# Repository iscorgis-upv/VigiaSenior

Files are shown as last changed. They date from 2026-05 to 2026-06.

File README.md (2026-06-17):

# VigiaSenior

<p align="center">
  <strong>Programación de aula y desarrollo técnico de un backend IoT para el seguimiento de la medicación en personas mayores</strong>
</p>

<p align="center">
  <em>CFGS Desarrollo de Aplicaciones Web (DAW) · Módulo 0613 - Desarrollo web en entorno servidor</em>
</p>

---
> **Nota de navegación**  
> Este README resume el contenido principal del repositorio, pero para revisar el proyecto con mejor estructura visual, navegación entre apartados y acceso ordenado a los materiales, se recomienda consultar la versión publicada en **GitHub Pages**:  
>  
> 👉 **https://iscorgis-upv.github.io/VigiaSenior/**  
>  
> El repositorio contiene muchos materiales conectados entre sí: documentación para profesorado, materiales para alumnado, implementación técnica, presentación, hardware y simulación. GitHub Pages facilita bastante su lectura.

---

## 🧭 Introducción

Este repositorio recoge una programación de aula del **CFGS de Desarrollo de Aplicaciones Web (DAW)** para el módulo **0613 · Desarrollo web en entorno servidor**. En esta propuesta didáctica se desarrolla el proyecto **VigiaSenior**, articulado a partir de una unidad de trabajo basada en el diseño e implementación del **backend de un pastillero inteligente**, pensado para apoyar el seguimiento de la medicación en personas mayores.

La propuesta parte de un problema real y reconocible: La dificultad de mantener rutinas de medicación seguras, controladas y registrables en contextos de envejecimiento, dependencia o supervisión familiar. A partir de ese contexto, el alumnado desarrolla una solución tecnológica en la que convergen análisis, modelado de datos, servicios web, lógica de negocio, persistencia, documentación e integración básica con hardware o simulación.

> **El repositorio tiene dos objetivos principales:**
>
> - Servir como **programación de aula transferible**, para que otro docente pueda comprenderla y aplicarla con pocas modificaciones.
> - Actuar como **repositorio técnico del proyecto**, recogiendo backend, hardware, simulación, documentación técnica y materiales de apoyo.

## 🎓 Normativa y contexto académico

Para elaborar esta propuesta se ha tomado como referencia la normativa del sistema educativo y de Formación Profesional, así como la normativa específica del título de **Técnico Superior en Desarrollo de Aplicaciones Web** y la normativa curricular aplicable en la **Comunidad Valenciana**.

La normativa completa puede consultarse en [Contextualización y marco legal](./profesorado/02_contextualizacion_y_marco_legal.html).

| Campo | Descripción |
|---|---|
| Etapa | Formación Profesional |
| Ciclo | CFGS Desarrollo de Aplicaciones Web (DAW) |
| Módulo | 0613 · Desarrollo web en entorno servidor |
| Metodología principal | Aprendizaje Basado en Proyectos (ABP) |
| Enfoque complementario | Aprendizaje-Servicio (ApS) |
| Producto técnico | Backend IoT para seguimiento de medicación |

A nivel curricular, el proyecto encaja bien con el módulo porque reúne varias tareas habituales del desarrollo backend: Crear servicios web, trabajar con una base de datos, organizar la lógica de negocio y diseñar una API. El componente IoT se utiliza como contexto del problema, no como objetivo principal, y sirve para dar sentido a los eventos que recibe el sistema. Además, el alumnado debe documentar lo que hace y defender las decisiones tomadas en la exposición final.

## 🧩 Proyecto

En esta propuesta se desarrolla **VigiaSenior**, un backend para un pastillero inteligente pensado para ayudar en el seguimiento de la medicación en personas mayores. Se trata de un proyecto que parte de una necesidad real y da sentido a los contenidos del módulo mediante una aplicación práctica con trasfondo social.

Su encaje dentro de **Desarrollo web en entorno servidor** es claro, ya que permite trabajar servicios web, bases de datos, lógica de negocio, diseño de endpoints e integración de eventos procedentes de un dispositivo. En lugar de abordar estos contenidos por separado, se trabajan de manera conjunta dentro de un proyecto único, más cercano a una situación real de desarrollo.

## 🎯 Objetivos del proyecto

Con esta propuesta se pretende que el alumnado sea capaz de:

- Analizar un problema real y convertirlo en requisitos técnicos.
- Diseñar el modelo de dominio de una aplicación basada en eventos.
- Estructurar una API  coherente y documentada.
- Implementar la persistencia de datos mediante base de datos relacional.
- Desarrollar lógica de negocio en servidor.
- Integrar software y hardware en una arquitectura sencilla de IoT.
- Documentar el proyecto de forma clara, trazable y reutilizable.
- Presentar el proyecto y explicar por qué se han tomado las principales decisiones técnicas y didácticas.

## 🚀 Resultado esperado del proyecto

Al finalizar el proyecto, el alumnado habrá desarrollado una primera versión funcional del backend de VigiaSenior, capaz de gestionar la planificación diaria de tomas, recibir eventos simulados de un dispositivo y registrar lo que ocurre durante el seguimiento de la medicación.

El proyecto se apoya en un flujo funcional sencillo, pero suficientemente sólido para trabajarlo en el aula:

- Consulta de planificación diaria.
- Recepción de eventos del dispositivo.
- Registro de apertura de cajita.
- Confirmación de la toma.
- actualización del estado de la toma.
- Generación de alertas.
- Consulta básica de seguimiento e histórico.

### Endpoints principales del backend

```text
GET   /health
GET   /api/devices/:deviceId/schedule/today
POST  /api/devices/:deviceId/events
GET   /api/patients/:patientId/dashboard
GET   /api/patients/:patientId/alerts
PATCH /api/alerts/:alertId/resolve
```

## 🔌 Hardware del proyecto

La parte física se plantea en una versión simplificada y asumible para aula, basada en **Arduino Nano ESP32**. Se entrega al inicio del proyecto porque la finalidad principal de la propuesta es el **backend**, no la electrónica ni la configuración hardware.

Se ha elegido una placa basada en ESP32, como Arduino Nano ESP32, porque ofrece un equilibrio muy adecuado entre coste, tamaño y conectividad. Es una opción asequible y fácil de conseguir, también en versiones compatibles de bajo coste, lo que la hace razonable para el contexto academico.

Además, su tamaño reducido encaja mejor en un prototipo de pastillero que otras alternativas más voluminosas, y además integra Wi-Fi y Bluetooth en la propia placa. Esto simplifica mucho el proyecto, ya que evita recurrir a módulos externos adicionales o a soluciones más costosas y complejas, como podría ocurrir con otras placas o con una Raspberry Pi.

### Configuración del prototipo

- 6 pulsadores o sensores para simular la apertura de las cajitas;
- 6 LEDs de estado;
- 1 botón de confirmación;
- 1 buzzer;
- conexión Wi‑Fi en la versión con backend.

### Esquema Propuesto

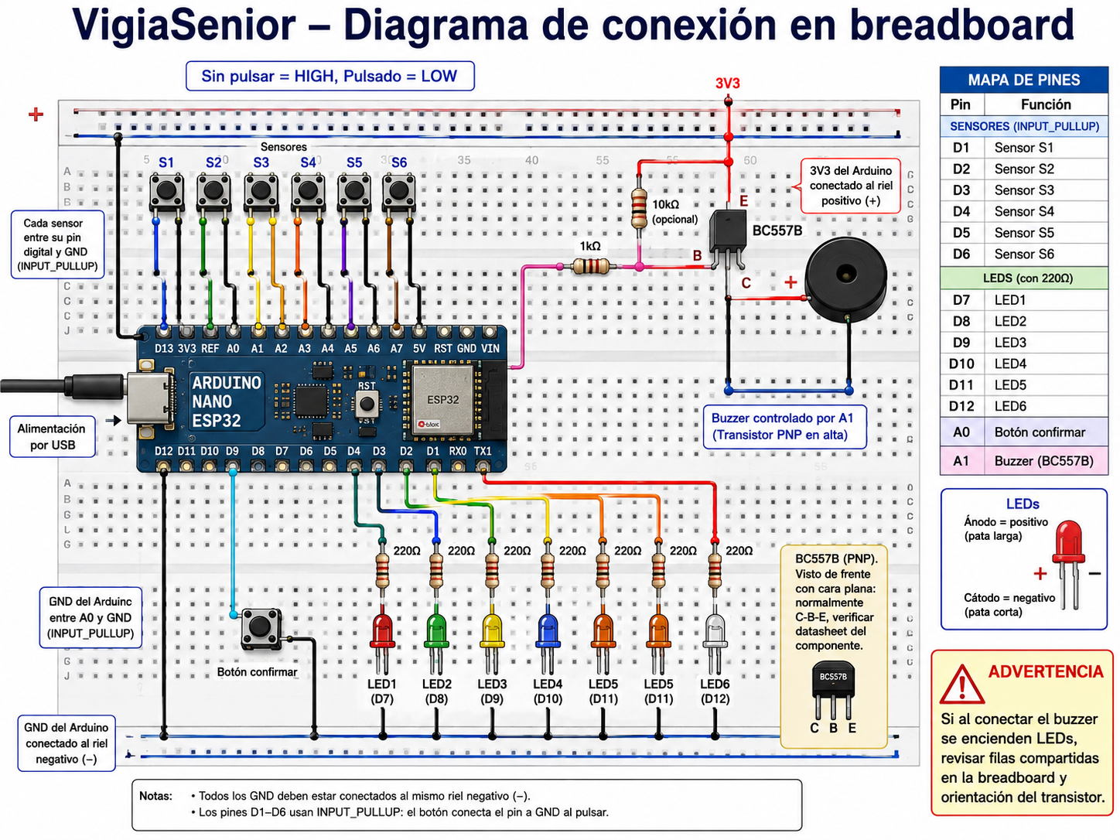
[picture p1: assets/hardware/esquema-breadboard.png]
Esquema de conexión en breadboard


## 🗂️ Estructura del repositorio

La estructura del repositorio se ha organizado para que la parte **didáctica** y la parte **técnica** convivan sin mezclarse.

```text
VigiaSenior/
├── alumnado/
├── profesorado/
├── presentacion/
├── implementacion/
├── LICENSE
└── README.md
```

| Carpeta | Contenido |
|---|---|
| 📘 profesorado/ | Guía didáctica, contextualización, programación de aula, currículo, metodología, DUA, instrumentos y rúbricas. |
| 👨‍🎓 alumnado/ | Dossier, enunciado, fases y entregables, tutoriales y plantillas de análisis, API y documentación. |
| ⚙️ implementacion/ | Backend, documentación técnica, hardware, prompts, recursos auxiliares y simulación. |

## 🧰 Materiales incluidos

### Para profesorado:

- Guía didáctica
- Programación de aula
- Contextualización
- Currículo y relación RA/CE
- Metodología y DUA
- Evaluación y rúbricas

### Para alumnado:

- Dossier del proyecto
- Enunciado
- Fases y entregables
- Tutoriales
- Plantillas

### Para la implementación:

- Backend
- Sketches Arduino
- Esquemas de conexión
- Documentación técnica
- Recursos de simulación

## 🛠️ Flujo de trabajo recomendado

El proyecto se plantea como un trabajo progresivo. Primero se entiende el problema y se concreta qué debe hacer el sistema. Después se identifican los datos principales, los eventos que puede recibir el backend y las reglas básicas que debe aplicar.

A partir de ahí, el alumnado diseña una primera versión de la API, implementa el backend por partes y va comprobando su funcionamiento con pruebas sencillas. La simulación del dispositivo o el montaje físico sirven para dar contexto al proyecto, pero no son el centro de la evaluación.

La parte final se dedica a ordenar la documentación, revisar el trabajo realizado y preparar una presentación breve en la que cada grupo explique qué ha construido, qué decisiones ha tomado y qué partes mejoraría si continuara el desarrollo.

## 🧠 Metodología de aula

La propuesta se apoya en una metodología basada en:

- Aprendizaje basado en proyectos
- Resolución de un problema significativo
- Trabajo cooperativo en grupos de 3
- Desarrollo incremental por fases
- Uso de GitHub como herramienta de trazabilidad y documentación
- Revisión progresiva de entregables

La parte técnica no se plantea como una simple acumulación de código, sino como un producto que debe ser **comprensible, justificable y transferible**.

## 📏 Evaluación

La evaluación no se plantea como una simple comprobación de si el backend “funciona” o no. El funcionamiento técnico es importante, pero se valora dentro de un conjunto más amplio de evidencias que permiten comprobar cómo ha trabajado el grupo y cómo ha justificado sus decisiones.

A lo largo del proyecto se recogerán distintas evidencias evaluables: el análisis inicial del problema, el diseño del modelo de datos, la definición de la API, la implementación del backend, las pruebas realizadas, la documentación técnica y la presentación final.

Estas evidencias permiten valorar especialmente:

- Si el alumnado comprende el problema planteado y lo traduce a una solución técnica viable
- Si el modelo de datos, la API y la lógica del backend son coherentes entre sí.
- Si el grupo prueba el sistema y corrige errores de forma razonada
- Si la documentación permite entender el trabajo realizado
- Si la presentación final explica con claridad las decisiones tomadas, las dificultades encontradas y las posibles mejoras

Las rúbricas y criterios de evaluación se encuentran en la carpeta [profesorado/](./profesorado/).

## 🧾 Cómo leer este repositorio

Si es la primera vez que accedes al proyecto, el orden de lectura recomendado es:

1. esta portada;
2. [Profesorado/](./profesorado/)
3. [Alumnado/](./alumnado/)
4. [Presentacion/](./presentacion/VigiaSenior%20Aula%20basada%20en%20proyecto%20y%20backend%20de%20pastillero%20inteligente-8.pdf)
5. [Implementacion/backend/](./implementacion/backend/)
6. [Implementacion/hardware/](./implementacion/hardware/)
7. [Implementacion/docs/](./implementacion/docs/)

## ⚖️ Licencia y reutilización

El repositorio incluye una licencia en el archivo `LICENSE`.

En caso de reutilización docente, se recomienda mantener la atribución del proyecto y respetar el carácter académico de los materiales, especialmente de aquellos concebidos como propuesta transferible para aula.

## ✅ Cierre

**VigiaSenior** se plantea como una propuesta de aula con valor técnico, sentido social y estructura pedagógica clara. El objetivo no es únicamente construir un backend funcional, sino convertir ese desarrollo en una experiencia de aprendizaje coherente, bien documentada, evaluable y reutilizable.

En este sentido, el repositorio pretende ser algo más que un contenedor de archivos: busca actuar como una **maleta pedagógica y técnica**, preparada para ser comprendida, adaptada, aplicada y defendida.

<p align="center">
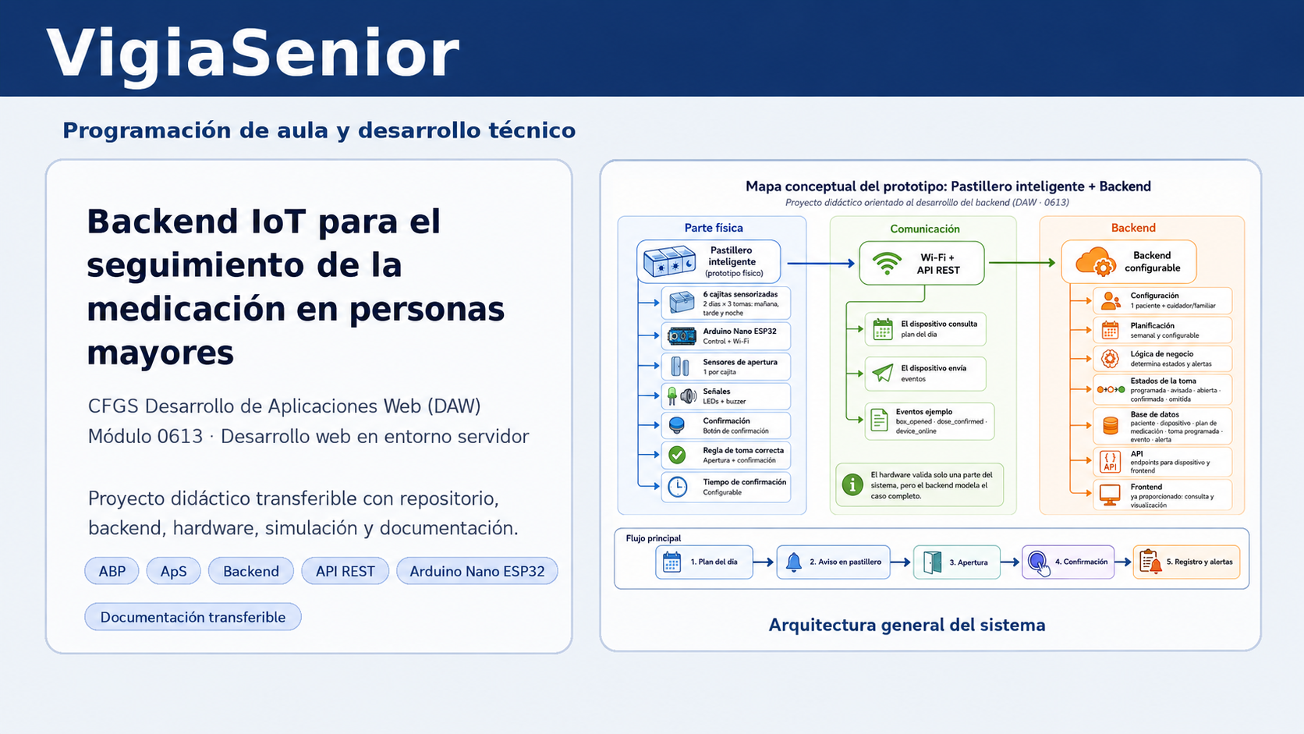
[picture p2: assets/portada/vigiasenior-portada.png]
Portada VigiaSenior
  
</p>

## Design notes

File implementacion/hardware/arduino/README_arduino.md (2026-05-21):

# Scripts Arduino de VigiaSenior

## Archivos
- `VigiaSenior_backend_mode.ino`: conecta al Wi‑Fi y al backend
- `VigiaSenior_test_mode_sin_backend.ino`: pruebas locales sin backend

## Mapeo fijo
- D1..D6 -> sensores/pulsadores de cajitas
- D7..D12 -> LEDs
- A0 -> botón confirmar
- A1 -> buzzer con BC557B (PNP)

## Carpeta recomendada en el repositorio
Colócalos en:

```text
hardware/arduino/
├── VigiaSenior_backend_mode/
│   └── VigiaSenior_backend_mode.ino
├── VigiaSenior_test_mode_sin_backend/
│   └── VigiaSenior_test_mode_sin_backend.ino
└── README_arduino.md
```

## Nota
En Arduino IDE conviene que el nombre de la carpeta coincida con el nombre del `.ino`.

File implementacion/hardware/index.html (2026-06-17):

# Hardware

Montaje físico, esquemas de apoyo y sketches Arduino.

VigiaSeniorImplementación técnica

← Volver al inicio

Hardware

# Montaje y sketches

La parte física sirve para generar eventos y entender el flujo del pastillero. No se evalúa como proyecto de electrónica avanzado.

### Notas de conexión

Resumen de pines, sensores, LEDs, confirmación y buzzer.

Abrir

### Sketch con backend

Versión preparada para enviar eventos a la API.

Abrir .ino

### Sketch de prueba local

Versión útil para probar el flujo sin WiFi ni servidor.

Abrir .ino

## Esquemas disponibles

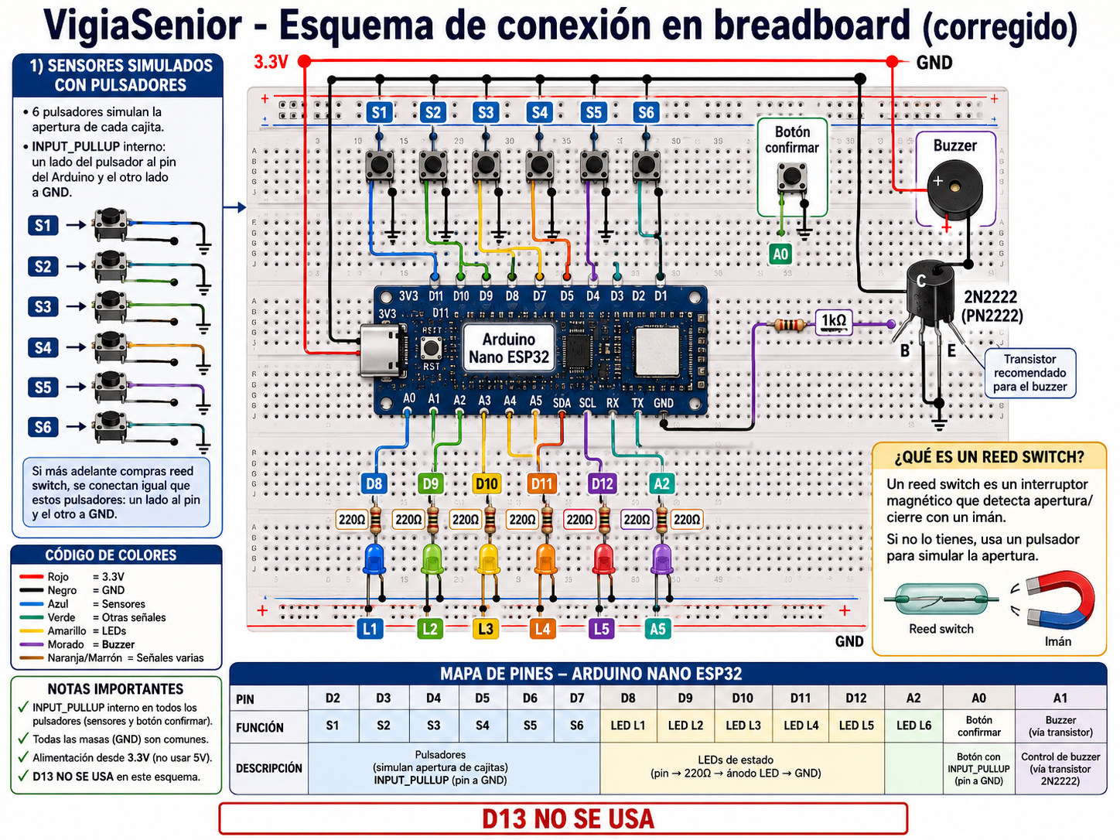
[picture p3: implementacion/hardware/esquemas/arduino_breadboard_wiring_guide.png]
Guía de cableado Arduino


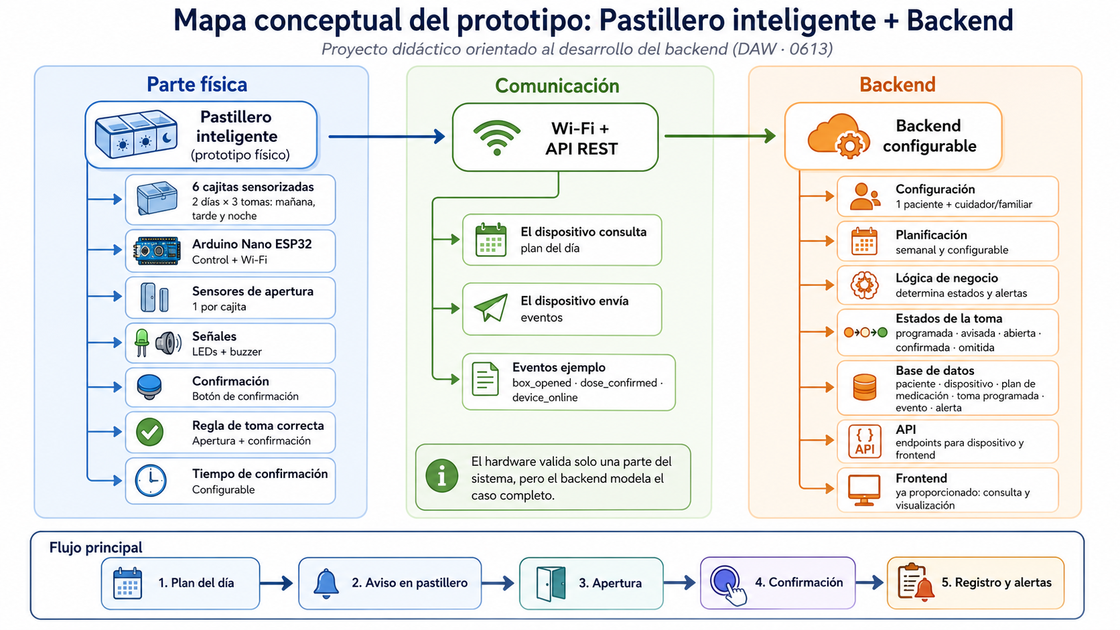
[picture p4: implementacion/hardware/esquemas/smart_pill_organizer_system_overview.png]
Vista general del sistema


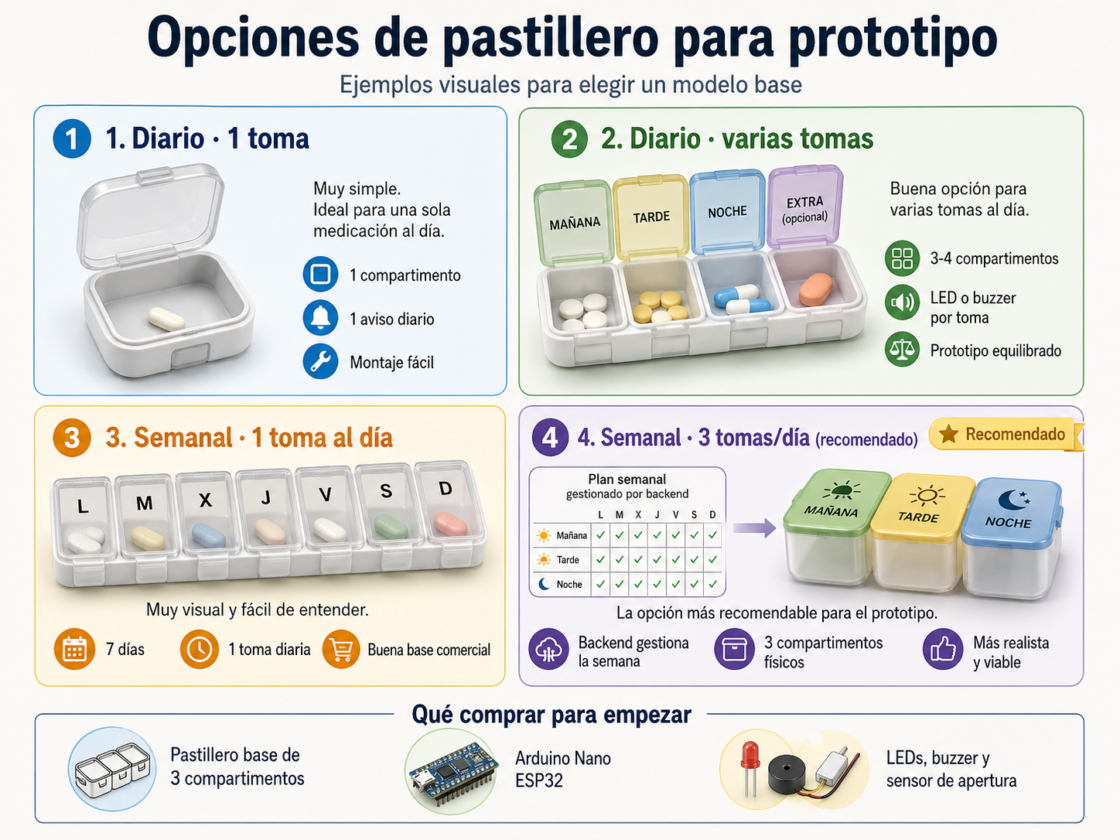
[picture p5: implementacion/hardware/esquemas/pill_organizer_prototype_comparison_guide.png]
Comparativa del prototipo


VigiaSenior · Implementación técnica

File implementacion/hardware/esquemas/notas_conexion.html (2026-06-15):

# Notas de conexión

Documento convertido a HTML para que pueda consultarse desde GitHub Pages sin depender de visores externos.

VigiaSeniorImplementación técnica

← Volver al inicio

# Notas de conexión

## Sensores/pulsadores

- un terminal del pulsador al pin digital
- el otro a GND
- usar INPUT_PULLUP en código

## LEDs

- pin digital -> resistencia 220Ω -> ánodo LED
- cátodo LED -> GND

## Botón confirmar

- un lado a A0
- otro a GND

## Buzzer con BC557B

- emisor a 3.3V
- base a A1 a través de 1kΩ
- colector al positivo del buzzer
- negativo del buzzer a GND

VigiaSenior · Implementación técnica

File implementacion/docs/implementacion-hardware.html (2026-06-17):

# Implementación hardware

Documento convertido a HTML para que pueda consultarse desde GitHub Pages sin depender de visores externos.

VigiaSeniorImplementación técnica

← Volver al inicio

# Implementación hardware

## Introducción

La parte hardware de VigiaSenior se ha planteado como una aproximación funcional y didáctica al comportamiento de un pastillero inteligente. No se pretende desarrollar un dispositivo industrial completo, sino disponer de un soporte físico o simulado que permita al alumnado comprender la relación entre el dispositivo y el backend.

Por este motivo, la implementación hardware se ha simplificado y orientado a la exploración de eventos, estados y flujos de interacción.

## Objetivo de la parte hardware

La finalidad principal del hardware dentro del proyecto es:

- simular o registrar aperturas de cajitas
- permitir la confirmación de una toma
- ofrecer señales visuales y acústicas básicas
- enviar eventos al backend o reproducir el flujo localmente
- servir como recurso de apoyo para comprender la lógica del sistema.

En consecuencia, el protagonismo del proyecto sigue estando en el backend, no en la electrónica.

## Placa y entorno de trabajo

La implementación se ha apoyado en una placa Arduino Nano ESP32 o, en el caso de simulación, en una placa virtual equivalente en entornos como Wokwi.

Esta elección permite:

- conectividad Wi‑Fi
- facilidad de programación
- disponibilidad de simulación
- integración sencilla con una API REST.

## Componentes principales del prototipo

La versión planteada del prototipo utiliza los siguientes elementos:

- 6 pulsadores o sensores para simular la apertura de 6 cajitas
- 6 LEDs de estado
- 1 botón de confirmación
- 1 buzzer
- cableado básico y placa de pruebas
- conexión Wi‑Fi en la versión integrada con backend.

## Mapeo de pines

El mapeo adoptado para el prototipo es el siguiente:

- D1–D6 → sensores o pulsadores de las cajitas
- D7–D12 → LEDs asociados a las cajitas
- A0 → botón de confirmación
- A1 → buzzer.

Este mapeo se ha mantenido fijo para facilitar la relación entre documentación, sketches y pruebas.

### Esquema Propuesto

Esquema de conexión en breadboard

## Funcionamiento esperado

El comportamiento básico del prototipo es el siguiente:

1. se activa una toma programada
2. el sistema indica visual o acústicamente la necesidad de realizar la toma;
3. el usuario abre la cajita correspondiente
4. el sistema registra la apertura
5. el usuario confirma la toma mediante el botón
6. el backend o la lógica local determinan si la toma es correcta.

## Modos de trabajo

La implementación hardware se ha contemplado en dos modos principales.

### 1. Modo sin backend

En este modo, el prototipo funciona de forma local y permite explorar:

- activación de una toma
- apertura correcta o incorrecta
- confirmación;
- timeout;
- comportamiento de LEDs y buzzer
- salida por monitor serie

Este modo resulta útil para pruebas iniciales, sesiones exploratorias y actividades del alumnado sin dependencia de red ni servidor.

### 2. Modo con backend

En este modo, el dispositivo se conecta por Wi‑Fi y envía eventos al backend.

Los eventos principales que se manejan son:

- device_online
- heartbeat
- box_opened
- dose_confirmed

Este modo permite comprobar la integración real entre dispositivo y backend.

## Simulación virtual

Además del montaje físico, el proyecto contempla simulaciones en Wokwi, con el fin de:

- facilitar la exploración por parte del alumnado
- evitar depender exclusivamente del hardware real
- reproducir el comportamiento del sistema desde un navegador;
- experimentar con sensores, LEDs, buzzer y eventos

La simulación se considera especialmente útil en contextos de aula donde no todos los equipos dispongan del prototipo físico completo.

## Relación con el backend

La parte hardware está subordinada a la lógica general del backend. Es decir, el dispositivo no decide por sí mismo cuándo una toma es correcta, sino que:

- detecta interacciones
- registra o envía eventos
- consulta la planificación diaria
- delega en el backend la interpretación funcional de dichos eventos.

Esta decisión es importante porque mantiene el foco del proyecto en la capa servidor.

## Valor didáctico

La implementación hardware aporta valor al proyecto por varias razones:

- da contexto real al backend
- favorece la comprensión del enfoque IoT
- permite visualizar eventos y respuestas del sistema
- incrementa la motivación del alumnado
- refuerza la relación entre software, datos y comportamiento físico.

## Conclusión

La parte hardware de VigiaSenior se ha concebido como un recurso de apoyo técnico y didáctico, no como un fin en sí mismo. Su presencia en el proyecto sirve para contextualizar el backend, enriquecer la experiencia de aprendizaje y aportar una dimensión práctica al desarrollo de la API y de la lógica de negocio.

VigiaSenior · Implementación técnica

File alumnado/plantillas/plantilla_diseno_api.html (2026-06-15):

# Plantilla de diseño de API

Plantilla editable para el trabajo del equipo.

VigiaSeniorAlumnado

← Volver al inicio

# Plantilla de diseño de API

## Endpoint

## Objetivo

## Método

## Parámetros

## Cuerpo de la petición

## Respuesta esperada

## Errores posibles

## Observaciones

Descargar plantilla .md

VigiaSenior · Alumnado

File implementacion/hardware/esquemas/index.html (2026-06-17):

# Esquemas de conexión

Notas y recursos visuales del prototipo.

VigiaSeniorImplementación técnica

← Volver al inicio

Esquemas

# Esquemas de conexión

Imágenes y notas para revisar el montaje sin depender de archivos sueltos.

## Notas de conexión

Abrir notas

VigiaSenior · Implementación técnica

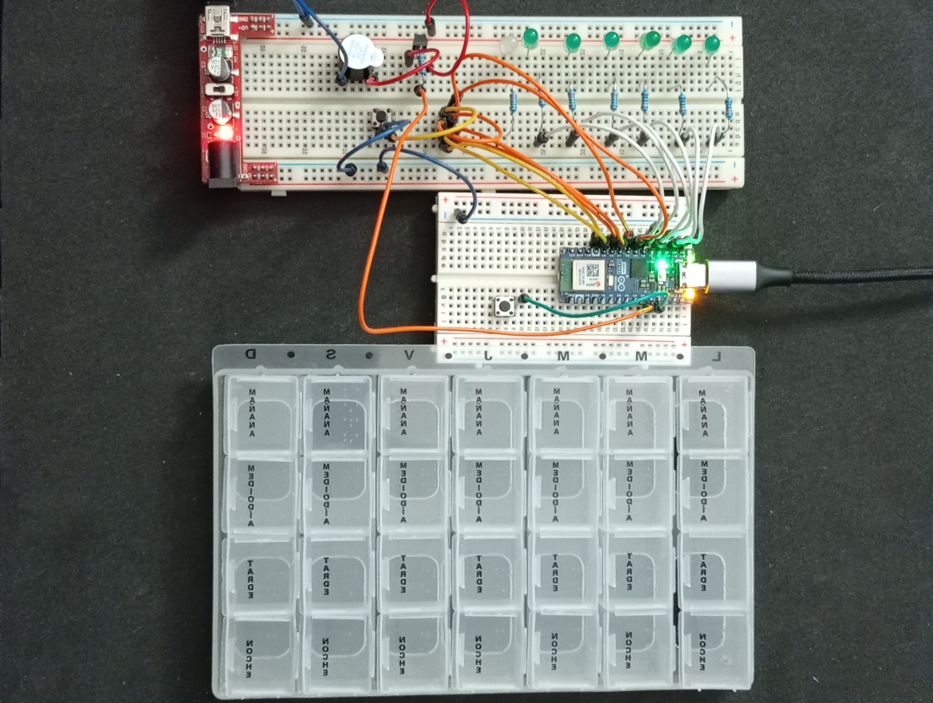
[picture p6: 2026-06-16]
assets/hardware/VigiaSenior_prototipo.png

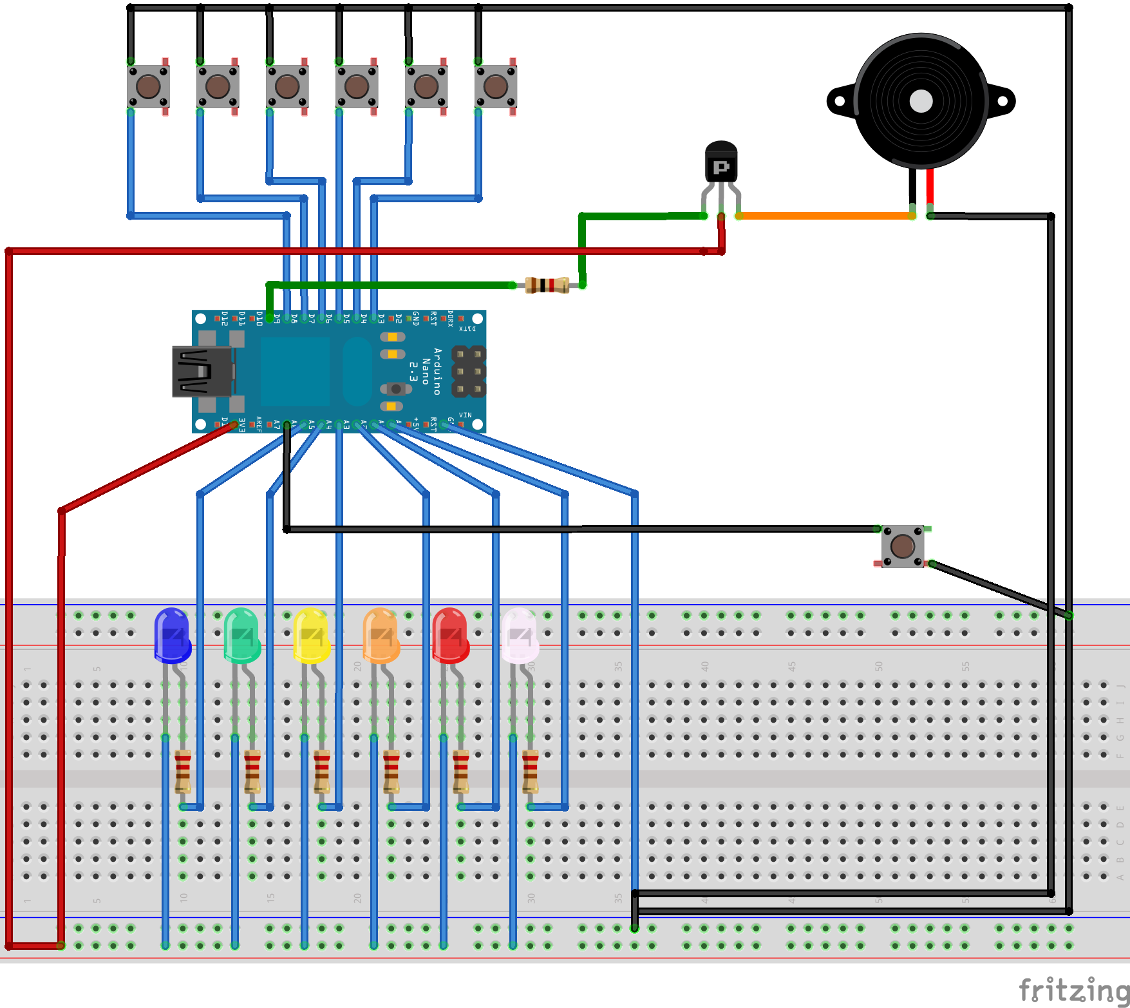
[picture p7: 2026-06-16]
implementacion/hardware/esquemas/VigiaSenior_fritzing.png

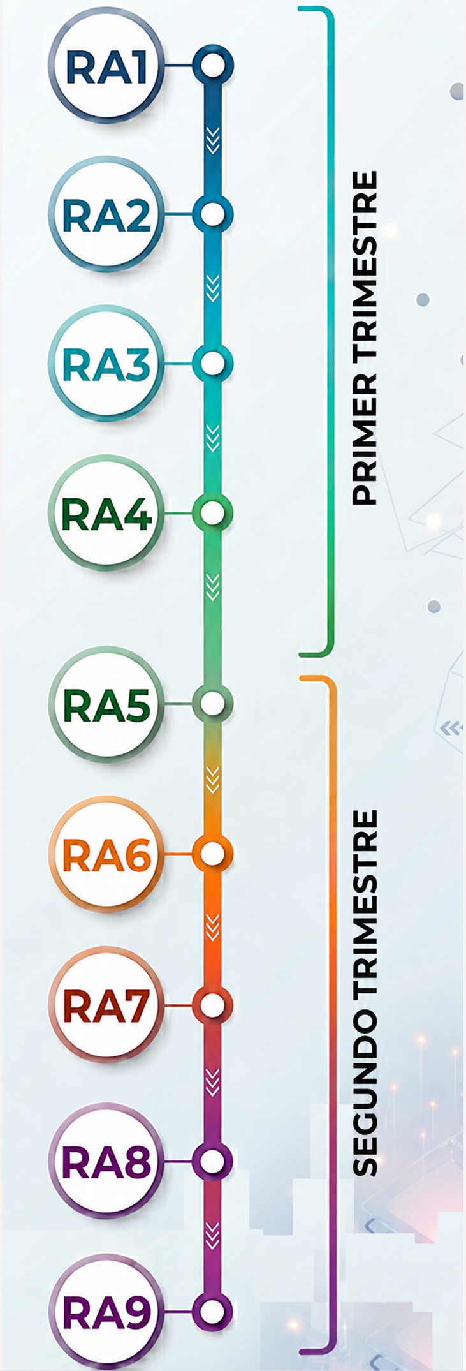
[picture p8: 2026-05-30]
assets/curriculum/bloques-unidades-programacion-ra.png

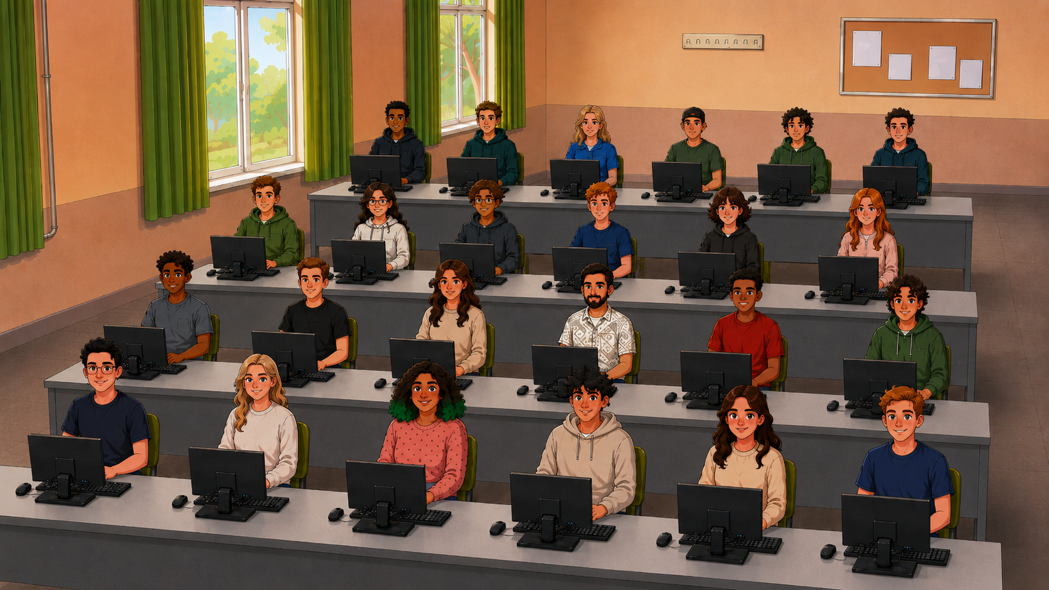
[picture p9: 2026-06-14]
assets/aula/clase.png

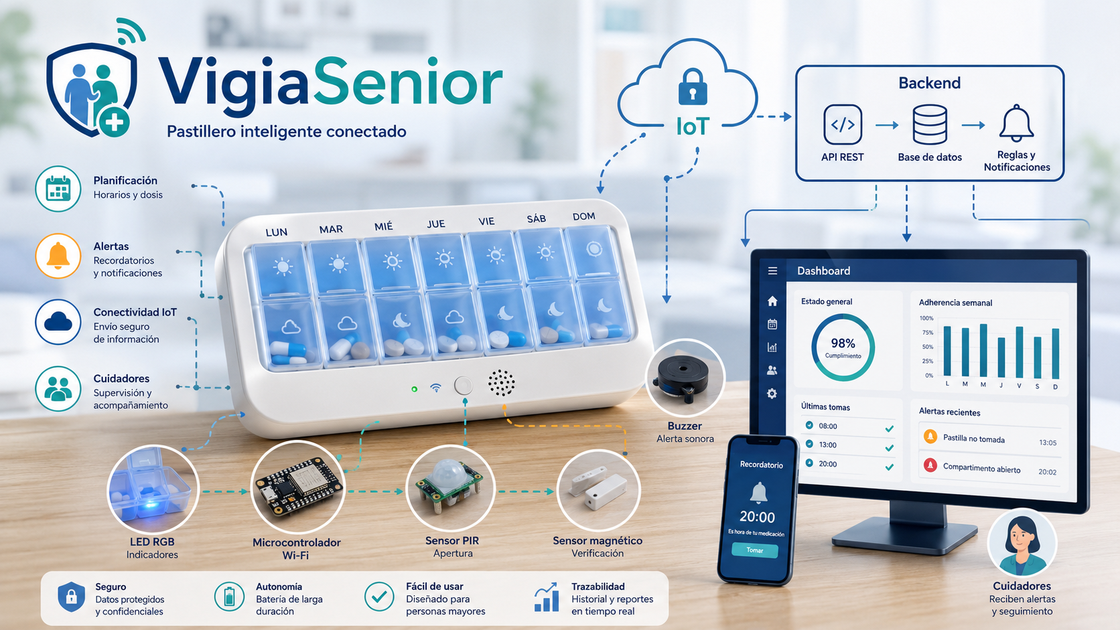
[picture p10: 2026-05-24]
assets/presentacion/diapositiva-portada.png

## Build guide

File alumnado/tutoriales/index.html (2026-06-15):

# Tutoriales

Material de apoyo para el alumnado.

VigiaSeniorAlumnado

← Volver al inicio

### Tutorial básico del backend

Primeros pasos con el stack y los endpoints mínimos.

Abrir

VigiaSenior · Alumnado

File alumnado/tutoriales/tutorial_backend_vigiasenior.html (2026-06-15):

# Tutorial básico del backend

Guía rápida para empezar el backend sin atascarse en el primer paso.

VigiaSeniorAlumnado

← Volver al inicio

# Tutorial básico del backend

## Stack recomendado

- Node.js
- TypeScript
- Express
- Prisma
- base de datos relacional

## Endpoints mínimos

- GET /health
- GET /api/devices/:deviceId/schedule/today
- POST /api/devices/:deviceId/events
- GET /api/patients/:patientId/dashboard
- GET /api/patients/:patientId/alerts

## Recomendación

No intentéis hacerlo todo de una vez. Empezad por: 1. modelo del dominio 2. esquema de datos 3. endpoint de salud 4. endpoint de planificación 5. registro de eventos

VigiaSenior · Alumnado

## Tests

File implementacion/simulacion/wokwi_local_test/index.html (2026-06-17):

← Volver al inicio

VigiaSenior

# Wokwi · prueba local

Escenario de simulación en modo local para apoyar la comprensión del flujo IoT.

DAWBackendPropuesta transferible

## Qué representa este escenario

Este recurso permite simular el comportamiento básico del pastillero sin depender de un montaje físico completo. La finalidad no es sustituir el backend ni el análisis del problema, sino facilitar pruebas controladas y explicar de dónde salen los eventos que recibe la API.

## Archivos incluidos

  - diagram.json: define los componentes y conexiones del circuito simulado.
  - sketch.ino: contiene el comportamiento programado del dispositivo.
  - README.html: resume el uso del escenario y sus límites.

## Qué debería observar el alumnado

  - Qué acción del usuario genera cada evento.
  - Qué datos necesita el backend para interpretar esa acción.
  - Qué diferencia hay entre simular una entrada y registrar una toma real.
  - Qué limitaciones tiene la simulación respecto a un dispositivo físico.

VigiaSenior · Simulación

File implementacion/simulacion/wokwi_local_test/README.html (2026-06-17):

← Volver al inicio

VigiaSenior

# Wokwi · prueba local · README

Notas de uso del escenario de simulación.

DAWBackendPropuesta transferible

## Uso del escenario

Abre el proyecto en Wokwi o en el entorno compatible que se vaya a utilizar. Revisa primero el diagrama para identificar entradas y salidas. Después ejecuta el sketch y comprueba qué ocurre al activar cada entrada.

## Qué no demuestra esta simulación

La simulación no garantiza que un montaje físico vaya a funcionar igual, ni que el backend esté correctamente implementado. Solo permite aislar una parte del sistema y comprobar el flujo lógico. Por eso debe acompañarse de pruebas de API y documentación.

## Relación con la entrega

Si el equipo usa simulación, debe indicarlo en la memoria técnica y explicar qué parte del sistema se ha validado con ella. No pasa nada por no tener hardware real si el alcance se declara correctamente y las pruebas están bien documentadas.

VigiaSenior · Simulación

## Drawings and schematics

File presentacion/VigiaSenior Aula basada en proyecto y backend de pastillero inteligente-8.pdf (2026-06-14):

Programación de aula basada en proyecto. Desarrollo del backend de un pastillero inteligente.

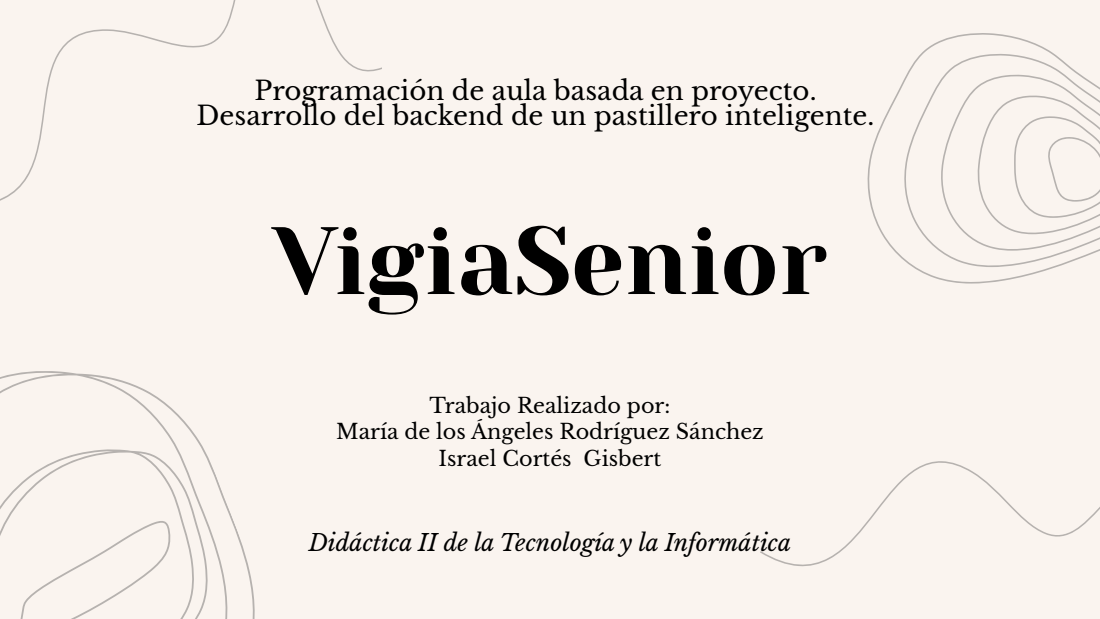
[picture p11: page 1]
VigiaSenior

Trabajo Realizado por:

María de los Ángeles Rodríguez Sánchez

Israel Cortés Gisbert

Didáctica II de la Tecnología y la Informática

# Índice

# 1.Contexto Académico 2.Marco Legal y Referencias Normativas 3.Módulo Profesional 4.Proyecto VigiaSenior

# Contexto Académico

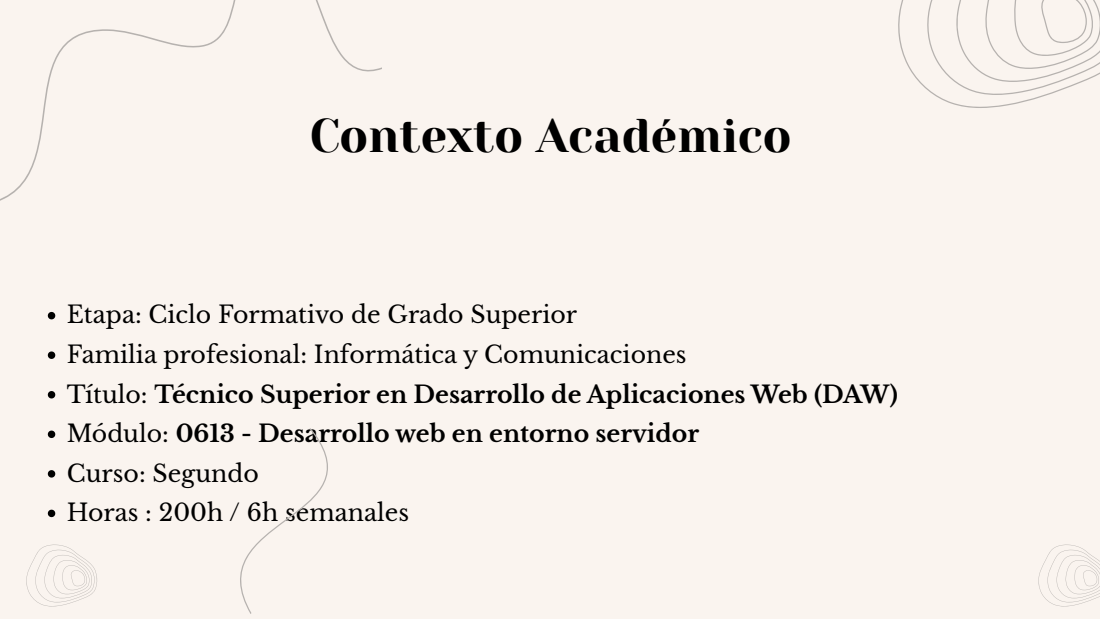
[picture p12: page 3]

Etapa: Ciclo Formativo de Grado Superior
Familia profesional: Informática y Comunicaciones
Título: Técnico Superior en Desarrollo de Aplicaciones Web (DAW)
Módulo: 0613 - Desarrollo web en entorno servidor
Curso: Segundo
Horas : 200h / 6h semanales

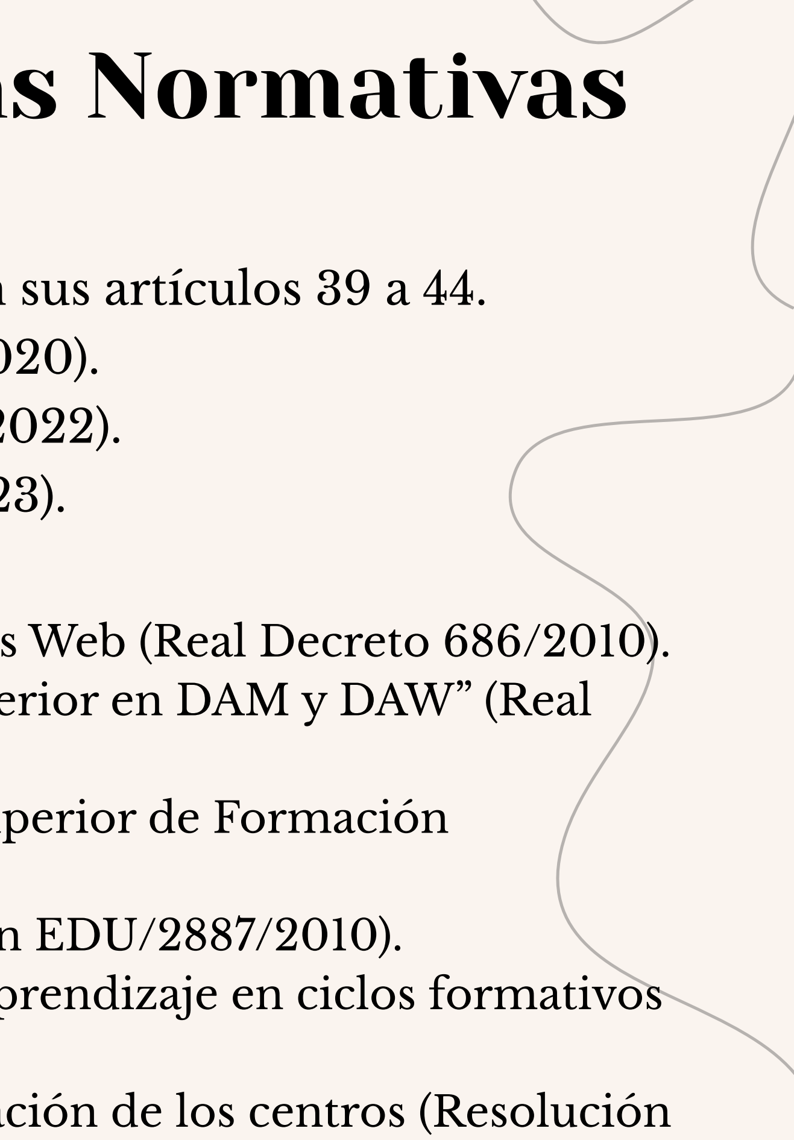
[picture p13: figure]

LOE (Ley Orgánica 2/2006), que se refiere a la FP en sus artículos 39 a 44. Está modificada por la LOMLOE (Ley Orgánica 3/2020).
Ordenación e integración de la FP (Ley Orgánica 3/2022).
Ordenación del sistema de FP (Real Decreto 659/2023).

# Normativa Básica

Título de Técnico Superior en Desarrollo de Aplicaciones Web (Real Decreto 686/2010).

## Modificado por

## “Actualización de Título de Técnico Superior en DAM y DAW” (Real

Decreto 405/2023).

## Currrículos de los ciclos formativos de grado medio y superior de Formación

Profesional (Decreto 114/2025).
Currículo del Título de Técnico Superior en DAW (Orden EDU/2887/2010).

## Regulación de la evaluación del proceso de enseñanza-aprendizaje en ciclos formativos

(Orden 8/2025).

## Instrucciones sobre ordenación académica y de organización de los centros (Resolución

de 17 de julio de 2025).

# Título y Currículo

# Marco Legal y Referencias Normativas

# Módulo 0613 - objetivos generales

c) Instalar módulos analizando su estructura y funcionalidad para gestionar servidores de aplicaciones.
d) Ajustar parámetros analizando la configuración para gestionar servidores de aplicaciones.
f) Seleccionar lenguajes, objetos y herramientas, interpretando las especificaciones para desarrollar aplicaciones web con acceso a bases de datos.
g) Utilizar lenguajes, objetos y herramientas, interpretando las especificaciones para desarrollar aplicaciones web con acceso a bases de datos.
h) Generar componentes de acceso a datos, cumpliendo las especificaciones, para integrar contenidos en la lógica de una aplicación web.
l) Utilizar herramientas y lenguajes específicos, cumpliendo las especificaciones, para desarrollar e integrar componentes software en el entorno del servidor web.
m) Emplear herramientas específicas, integrando la funcionalidad entre aplicaciones, para desarrollar servicios empleables en aplicaciones web.
n) Evaluar servicios distribuidos ya desarrollados, verificando sus prestaciones y funcionalidad, para integrar servicios distribuidos en una aplicación web.
ñ) Verificar los componentes de software desarrollados, analizando las especificaciones, para completar el plan de pruebas. o) Utilizar herramientas específicas, cumpliendo los estándares establecidos, para elaborar y mantener la documentación de los procesos.
q) Programar y realizar actividades para gestionar el mantenimiento de los recursos informáticos.
s) Desarrollar la creatividad y el espíritu de innovación para responder a los retos que se presentan en los procesos y organización de trabajo y de la vida personal.
t) Tomar decisiones de forma fundamentada analizando las variables implicadas, integrando saberes de distinto ámbito y aceptando los riesgos y la posibilidad de equivocación en las mismas, para afrontar y resolver distintas situaciones, problemas o contingencias.
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

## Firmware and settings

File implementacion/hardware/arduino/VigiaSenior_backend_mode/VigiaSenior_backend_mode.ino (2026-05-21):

#include <WiFi.h>
#include <HTTPClient.h>

// ==============================
// VigiaSenior - modo con backend
// Arduino Nano ESP32
// Sensores: D1..D6
// LEDs:     D7..D12
// Confirm:  A0
// Buzzer:   A1
// ==============================

// --- CONFIGURACIÓN WIFI / BACKEND ---
const char* WIFI_SSID = "TU_WIFI";
const char* WIFI_PASSWORD = "TU_PASSWORD";
const char* BACKEND_BASE_URL = "http://192.168.1.34:3000"; // cambia esto
const char* DEVICE_ID = "pillbox-001";

// --- MAPA DE PINES ---
const uint8_t SENSOR_PINS[6] = {1, 2, 3, 4, 5, 6};     // D1..D6
const uint8_t LED_PINS[6]    = {7, 8, 9, 10, 11, 12};  // D7..D12
const uint8_t CONFIRM_PIN    = A0;
const uint8_t BUZZER_PIN     = A1;

// --- TIEMPOS ---
const unsigned long DEBOUNCE_MS = 50;
const unsigned long HEARTBEAT_MS = 30000;

// --- ESTADO ---
bool sensorStable[6];
bool sensorRawLast[6];
unsigned long sensorLastChange[6];

bool confirmStable = HIGH;
bool confirmRawLast = HIGH;
unsigned long confirmLastChange = 0;

unsigned long lastHeartbeat = 0;
int lastOpenedSlot = -1;

// ==============================
// UTILIDADES
// ==============================
void beep(unsigned int durationMs = 80) {
  digitalWrite(BUZZER_PIN, HIGH);
  delay(durationMs);
  digitalWrite(BUZZER_PIN, LOW);
}

void blinkLed(uint8_t idx, int times = 2, int onMs = 100, int offMs = 70) {
  if (idx >= 6) return;
  for (int i = 0; i < times; i++) {
    digitalWrite(LED_PINS[idx], HIGH);
    delay(onMs);
    digitalWrite(LED_PINS[idx], LOW);
    delay(offMs);
  }
}

bool ensureWifi() {
  if (WiFi.status() == WL_CONNECTED) return true;

  Serial.println("[WiFi] reconectando...");
  WiFi.begin(WIFI_SSID, WIFI_PASSWORD);

  unsigned long start = millis();
  while (WiFi.status() != WL_CONNECTED && millis() - start < 10000) {
    delay(400);
    Serial.print(".");
  }
  Serial.println();

  if (WiFi.status() == WL_CONNECTED) {
    Serial.print("[WiFi] conectada. IP: ");
    Serial.println(WiFi.localIP());
    return true;
  }

  Serial.println("[WiFi] no conectada");
  return false;
}

String makeEventBody(const char* eventType, int physicalSlot = -1) {
  String body = "{";
  body += "\"deviceId\":\"" + String(DEVICE_ID) + "\",";
  body += "\"eventType\":\"" + String(eventType) + "\",";
  if (physicalSlot > 0) {
    body += "\"physicalSlot\":" + String(physicalSlot);
  } else {
    body += "\"physicalSlot\":null";
  }
  body += "}";
  return body;
}

bool postEvent(const char* eventType, int physicalSlot = -1) {
  if (!ensureWifi()) return false;

  HTTPClient http;
  String url = String(BACKEND_BASE_URL) + "/api/devices/" + DEVICE_ID + "/events";
  String body = makeEventBody(eventType, physicalSlot);

  http.begin(url);
  http.addHeader("Content-Type", "application/json");

  Serial.print("[POST] ");
  Serial.println(url);
  Serial.print("[BODY] ");
  Serial.println(body);

  int code = http.POST(body);
  String response = http.getString();

  Serial.print("[HTTP] code: ");
  Serial.println(code);
  Serial.print("[HTTP] response: ");
  Serial.println(response);

  http.end();
  return code >= 200 && code < 300;
}

void getHealth() {
  if (!ensureWifi()) return;

  HTTPClient http;
  String url = String(BACKEND_BASE_URL) + "/health";
  http.begin(url);
  int code = http.GET();
  String response = http.getString();

  Serial.print("[GET /health] code: ");
  Serial.println(code);
  Serial.println(response);
  http.end();
}

void getTodaySchedule() {
  if (!ensureWifi()) return;

  HTTPClient http;
  String url = String(BACKEND_BASE_URL) + "/api/devices/" + DEVICE_ID + "/schedule/today";
  http.begin(url);
  int code = http.GET();
  String response = http.getString();

  Serial.print("[GET schedule] code: ");
  Serial.println(code);
  Serial.println(response);
  http.end();
}

// ==============================
// SETUP
// ==============================
void setup() {
  Serial.begin(115200);
  delay(800);

  pinMode(BUZZER_PIN, OUTPUT);
  digitalWrite(BUZZER_PIN, LOW);

  pinMode(CONFIRM_PIN, INPUT_PULLUP);

  for (int i = 0; i < 6; i++) {
    pinMode(SENSOR_PINS[i], INPUT_PULLUP);
    pinMode(LED_PINS[i], OUTPUT);
    digitalWrite(LED_PINS[i], LOW);

    bool current = digitalRead(SENSOR_PINS[i]);
    sensorStable[i] = current;
    sensorRawLast[i] = current;
    sensorLastChange[i] = millis();
  }

  WiFi.mode(WIFI_STA);
  ensureWifi();

  beep(90);
  delay(80);
  beep(90);

  getHealth();
  getTodaySchedule();
  postEvent("device_online");

  lastHeartbeat = millis();

  Serial.println("=== VigiaSenior backend mode listo ===");
}

// ==============================
// LOOP
// ==============================
void loop() {
  ensureWifi();

  // Heartbeat
  if (millis() - lastHeartbeat >= HEARTBEAT_MS) {
    postEvent("heartbeat");
    lastHeartbeat = millis();
  }

  // Sensores: INPUT_PULLUP => LOW al pulsar/abrir
  for (int i = 0; i < 6; i++) {
    bool raw = digitalRead(SENSOR_PINS[i]);

    if (raw != sensorRawLast[i]) {
      sensorRawLast[i] = raw;
      sensorLastChange[i] = millis();
    }

    if ((millis() - sensorLastChange[i]) > DEBOUNCE_MS && raw != sensorStable[i]) {
      sensorStable[i] = raw;

      if (sensorStable[i] == LOW) {
        lastOpenedSlot = i + 1;
        Serial.print("[SLOT] apertura en cajita ");
        Serial.println(lastOpenedSlot);

        digitalWrite(LED_PINS[i], HIGH);
        beep(70);
        postEvent("box_opened", lastOpenedSlot);
      } else {
        digitalWrite(LED_PINS[i], LOW);
      }
    }
  }

  // Botón de confirmación: INPUT_PULLUP => LOW al pulsar
  bool confirmRaw = digitalRead(CONFIRM_PIN);
  if (confirmRaw != confirmRawLast) {
    confirmRawLast = confirmRaw;
    confirmLastChange = millis();
  }

  if ((millis() - confirmLastChange) > DEBOUNCE_MS && confirmRaw != confirmStable) {
    confirmStable = confirmRaw;

    if (confirmStable == LOW) {
      Serial.println("[BTN] confirmación");

      if (lastOpenedSlot > 0) {
        postEvent("dose_confirmed", lastOpenedSlot);
        blinkLed(lastOpenedSlot - 1, 3, 70, 50);
        beep(140);
      } else {
        Serial.println("[WARN] no hay slot abierto previo");
        beep(250);
      }
    }
  }

  delay(8);
}

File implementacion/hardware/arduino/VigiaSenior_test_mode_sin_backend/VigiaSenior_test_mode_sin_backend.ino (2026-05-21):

// ==============================
// VigiaSenior - modo sin backend
// Pruebas locales en breadboard
// Arduino Nano ESP32
//
// Sensores: D1..D6   (pulsadores simulando apertura)
// LEDs:     D7..D12
// Confirm:  A0
// Buzzer:   A1
// ==============================

const uint8_t SENSOR_PINS[6] = {1, 2, 3, 4, 5, 6};     // D1..D6
const uint8_t LED_PINS[6]    = {7, 8, 9, 10, 11, 12};  // D7..D12
const uint8_t CONFIRM_PIN    = A0;
const uint8_t BUZZER_PIN     = A1;

const unsigned long DEBOUNCE_MS = 50;
const unsigned long ALERT_INTERVAL_MS = 10000;   // cada cuánto empieza una alerta nueva
const unsigned long CONFIRM_WINDOW_MS = 12000;   // tiempo para abrir + confirmar

bool sensorStable[6];
bool sensorRawLast[6];
unsigned long sensorLastChange[6];

bool confirmStable = HIGH;
bool confirmRawLast = HIGH;
unsigned long confirmLastChange = 0;

enum DemoState {
  IDLE,
  ALERTING,
  OPENED
};

DemoState state = IDLE;
int activeSlot = 0;          // 0..5
int openedSlot = -1;         // 0..5
unsigned long stateStartedAt = 0;
unsigned long lastBlinkAt = 0;
bool blinkState = false;

void beep(unsigned int durationMs = 80) {
  digitalWrite(BUZZER_PIN, HIGH);
  delay(durationMs);
  digitalWrite(BUZZER_PIN, LOW);
}

void allLedsOff() {
  for (int i = 0; i < 6; i++) {
    digitalWrite(LED_PINS[i], LOW);
  }
}

void flashLed(uint8_t idx, int times = 2, int onMs = 100, int offMs = 70) {
  if (idx >= 6) return;
  for (int i = 0; i < times; i++) {
    digitalWrite(LED_PINS[idx], HIGH);
    delay(onMs);
    digitalWrite(LED_PINS[idx], LOW);
    delay(offMs);
  }
}

void startAlertForCurrentSlot() {
  state = ALERTING;
  openedSlot = -1;
  stateStartedAt = millis();
  lastBlinkAt = 0;
  blinkState = false;

  allLedsOff();
  Serial.print("[DEMO] toma activa en cajita ");
  Serial.println(activeSlot + 1);
  beep(120);
}

void goToNextSlot() {
  allLedsOff();
  activeSlot = (activeSlot + 1) % 6;
  state = IDLE;
  openedSlot = -1;
  stateStartedAt = millis();
}

void setup() {
  Serial.begin(115200);
  delay(600);

  pinMode(BUZZER_PIN, OUTPUT);
  digitalWrite(BUZZER_PIN, LOW);

  pinMode(CONFIRM_PIN, INPUT_PULLUP);

  for (int i = 0; i < 6; i++) {
    pinMode(SENSOR_PINS[i], INPUT_PULLUP);
    pinMode(LED_PINS[i], OUTPUT);
    digitalWrite(LED_PINS[i], LOW);

    bool current = digitalRead(SENSOR_PINS[i]);
    sensorStable[i] = current;
    sensorRawLast[i] = current;
    sensorLastChange[i] = millis();
  }

  beep(80);
  delay(80);
  beep(80);
  delay(80);
  beep(80);

  stateStartedAt = millis();

  Serial.println("=== VigiaSenior modo pruebas sin backend ===");
  Serial.println("Funcionamiento:");
  Serial.println("- cada cierto tiempo se activa una cajita");
  Serial.println("- el LED de esa cajita parpadea");
  Serial.println("- pulsa su sensor para simular apertura");
  Serial.println("- pulsa confirmar (A0) para validar la toma");
}

void loop() {
  // Lanzar siguiente alerta si estamos en IDLE
  if (state == IDLE && millis() - stateStartedAt >= ALERT_INTERVAL_MS) {
    startAlertForCurrentSlot();
  }

  // Debounce sensores
  for (int i = 0; i < 6; i++) {
    bool raw = digitalRead(SENSOR_PINS[i]);

    if (raw != sensorRawLast[i]) {
      sensorRawLast[i] = raw;
      sensorLastChange[i] = millis();
    }

    if ((millis() - sensorLastChange[i]) > DEBOUNCE_MS && raw != sensorStable[i]) {
      sensorStable[i] = raw;

      // INPUT_PULLUP => LOW al pulsar
      if (sensorStable[i] == LOW) {
        Serial.print("[SENSOR] pulsada cajita ");
        Serial.println(i + 1);

        if (state == ALERTING && i == activeSlot) {
          state = OPENED;
          openedSlot = i;
          allLedsOff();
          digitalWrite(LED_PINS[i], HIGH);
          stateStartedAt = millis();
          beep(70);
          Serial.println("[DEMO] apertura válida");
        } else {
          Serial.println("[DEMO] cajita incorrecta o fuera de tiempo");
          beep(250);
        }
      }
    }
  }

  // Debounce botón confirmar
  bool confirmRaw = digitalRead(CONFIRM_PIN);
  if (confirmRaw != confirmRawLast) {
    confirmRawLast = confirmRaw;
    confirmLastChange = millis();
  }

  if ((millis() - confirmLastChange) > DEBOUNCE_MS && confirmRaw != confirmStable) {
    confirmStable = confirmRaw;

    if (confirmStable == LOW) {
      Serial.println("[BTN] confirmación");

      if (state == OPENED && openedSlot == activeSlot) {
        Serial.println("[DEMO] toma confirmada correctamente");
        flashLed(activeSlot, 3, 70, 50);
        beep(150);
        goToNextSlot();
      } else {
        Serial.println("[DEMO] no hay apertura válida previa");
        beep(250);
      }
    }
  }

  // Parpadeo / alerta
  if (state == ALERTING) {
    if (millis() - lastBlinkAt >= 350) {
      lastBlinkAt = millis();
      blinkState = !blinkState;
      digitalWrite(LED_PINS[activeSlot], blinkState ? HIGH : LOW);

      if (blinkState) {
        digitalWrite(BUZZER_PIN, HIGH);
      } else {
        digitalWrite(BUZZER_PIN, LOW);
      }
    }

    if (millis() - stateStartedAt >= CONFIRM_WINDOW_MS) {
      digitalWrite(BUZZER_PIN, LOW);
      Serial.println("[DEMO] toma omitida por timeout");
      flashLed(activeSlot, 4, 40, 40);
      beep(300);
      goToNextSlot();
    }
  }

  // Timeout si abrió pero no confirmó
  if (state == OPENED) {
    if (millis() - stateStartedAt >= CONFIRM_WINDOW_MS) {
      Serial.println("[DEMO] apertura sin confirmación: timeout");
      allLedsOff();
      flashLed(activeSlot, 4, 40, 40);
      beep(300);
      goToNextSlot();
    }
  }

  delay(8);
}

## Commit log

2026-05-17 feat(alerts): implementado listado y resolución de alertas
2026-05-17 fix(backend): corrige errores de compilacion typescript
2026-05-21 docs(project): integra materiales didácticos hardware y organizacion contenido
2026-05-24 docs(project): reorganiza la estructura e integra la documentación y materiales del proyecto
    [ra_ce_contenidos_0613_pastillero.xlsx]
2026-05-24 docs(profesorado): añade anexo de secuenciación por sesiones
2026-05-25 docs(evaluacion): se añade hoja de ponderación por RA, evidencias y criterios
    [ponderacionRaCEyCriterios.xlsx]
2026-05-25 docs(readme): ajuste de introducción y contexto del proyecto
2026-05-26 docs(profesorado): añadidos ficheros de secuenciación por sesiones
2026-05-26 refactor: consolidar documentacion HTML de profesorado y alumnado
    [ponderacionRaCEyCriterios.xlsx]
2026-05-26 refactor: pulir textos de la capa profesor/alumnado
2026-05-26 docs: añadido enlaces de acceso rapido en README
2026-05-26 chore: eliminar cambios en el readme, generaban problemas con github pages
2026-05-26 ci: configurado despliegue de GitHub Pages
2026-05-26 refactor: pulir RA/CE en xlsx
    [ponderacionRaCEyCriterios.xlsx]
2026-05-27 docs: añade pagina inicial para GitHub Pages
2026-05-27 docs: añade portada visual para GitHub Pages
2026-05-27 docs: añadida presentacion pdf y refactor de index html alumnos y profesor
2026-05-27 docs: modificacion en el index.html de entrada
2026-05-27 docs: modificacion portada y header y correccion error RA/CE en la tabla.
2026-05-27 docs: mejora navegacion interna de GitHub Pages
2026-05-27 docs: añade boton inicio en la navegacion
2026-05-27 docs: cambios en la navegación
2026-05-30 docs: se añade bloques de programacion y RA
2026-06-15 docs(varios): modificar xlsx de evaluacion y mover .md a html para mejorar navegación
    [ponderacionRaCEyCriterios.xlsx]
2026-06-16 docs(general): modificación del contenido profesorado y esquema con fritzing
    [VigiaSeniorV2_esquema.fzz]
2026-06-16 docs(alumnado): modificación del contenido de los distintos html"
2026-06-16 docs(alumnado): error html en guia de sesiones
2026-06-17 docs(index.html): corrección link presentación tras cambio de versión
